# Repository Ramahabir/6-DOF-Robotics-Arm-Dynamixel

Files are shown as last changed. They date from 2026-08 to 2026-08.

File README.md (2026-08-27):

# STM32F411 6-DOF Robot Arm Controller

Firmware for a 6-degree-of-freedom robot arm based on an STM32F411CEU6 (Black Pill). The controller is designed to operate four Dynamixel joints over a half-duplex serial bus and two conventional PWM servos for the end effector.

The project uses STM32Cube HAL with PlatformIO and is uploaded/debugged through ST-Link.

## System overview

- **4 × Dynamixel joints** — controlled through USART2 using Dynamixel Protocol 1.0
- **1 × wrist/gripper rotation servo** — PWM output on PA8
- **1 × gripper servo** — PWM output on PA6
- **USB-to-TTL data logger** — connected through USART1
- **ESP32-C3 Super Mini** — planned wireless interface through USART6
- **74LS241 buffer** — converts the Dynamixel UART connection into a controlled half-duplex bus

## Hardware

- STM32F411CEU6 Black Pill development board
- Dynamixel AX-series actuators (the driver currently targets the AX-12A control table)
- 74LS241 tri-state buffer for the Dynamixel half-duplex bus
- Two PWM-compatible hobby servos
- USB-to-TTL serial adapter
- ST-Link programmer/debugger
- ESP32-C3 Super Mini (planned)
- Suitable external power supplies for the Dynamixel and hobby servos

## Controller PCB

The repository includes the editable KiCad source for the custom controller PCB. The board combines the STM32F411 Black Pill, ESP32-C3 Super Mini, 74LS241 Dynamixel interface, power input, actuator connectors, and development headers on one carrier board.

Open [`pcb/6dof.kicad_pro`](pcb/6dof.kicad_pro) in **KiCad 9.0 or newer** to view or modify the complete project.

### Schematic

<p align="center">
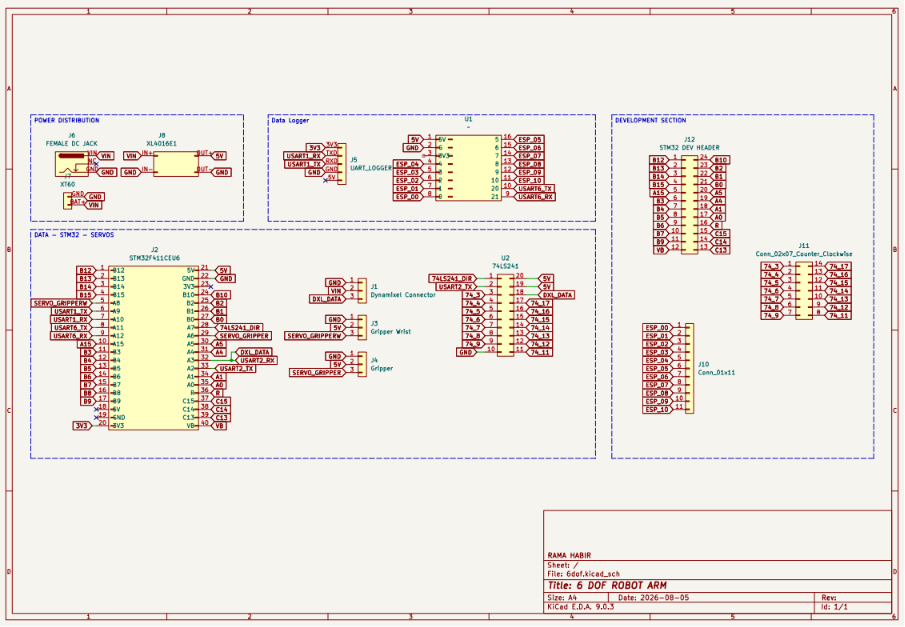
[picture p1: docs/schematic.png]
6-DOF robot arm controller schematic
  
</p>

Editable source: [`pcb/6dof.kicad_sch`](pcb/6dof.kicad_sch)

### PCB layout

<p align="center">
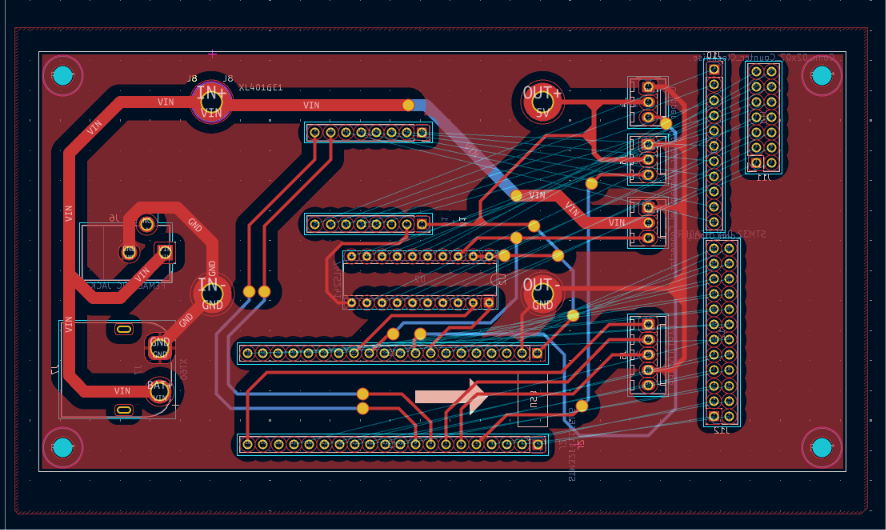
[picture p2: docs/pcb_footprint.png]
6-DOF robot arm controller PCB layout
  
</p>

Editable source: [`pcb/6dof.kicad_pcb`](pcb/6dof.kicad_pcb)

### 3D preview

<p align="center">
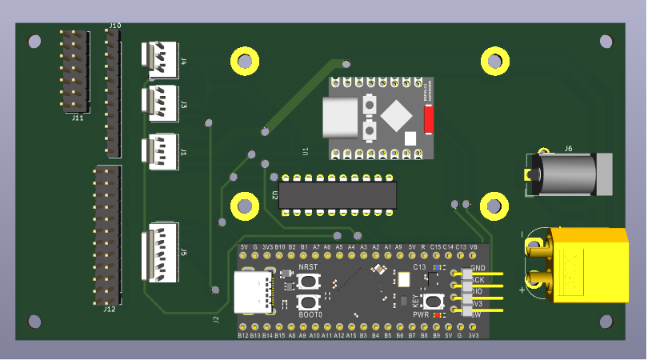
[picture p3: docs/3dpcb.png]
3D preview of the 6-DOF robot arm controller PCB
  
</p>

> The KiCad files are active design sources. Review the schematic, complete the design-rule checks, and verify all footprints and routing before ordering a PCB. Gerber files, drill files, and a bill of materials are not included yet.

## Pin assignment

<p align="center">
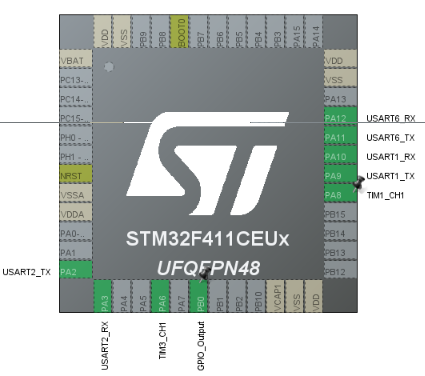
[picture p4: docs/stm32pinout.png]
STM32F411CEU6 robot arm controller pinout
  
</p>

| Function | STM32 peripheral | Pin | Direction | Notes |
|---|---|---:|---|---|
| Dynamixel TX | USART2_TX | PA2 | Output | 1 Mbps, 8-N-1 |
| Dynamixel RX | USART2_RX | PA3 | Input | Receives Dynamixel status packets |
| 74LS241 direction | GPIO | PB0 | Output | High = transmit, low = receive/bus released |
| Data logger TX | USART1_TX | PA9 | Output | Connect to USB-to-TTL RX |
| Data logger RX | USART1_RX | PA10 | Input | Connect to USB-to-TTL TX |
| ESP32-C3 TX | USART6_TX | PA11 | Output | Planned wireless link; connect to ESP32 RX |
| ESP32-C3 RX | USART6_RX | PA12 | Input | Planned wireless link; connect to ESP32 TX |
| Gripper rotation servo | TIM1_CH1 | PA8 | PWM output | Rotates the gripper |
| Gripper servo | TIM3_CH1 | PA6 | PWM output | Opens and closes the gripper |
| Built-in status LED | GPIO | PC13 | Output | Active-low on the Black Pill |

> The USART1 pin assignment above follows the target hardware pinout. The generated firmware currently maps USART1 to PB6/PB7; update the alternate-function configuration to PA9/PA10 before wiring the logger to those target pins.

## Dynamixel bus

Dynamixel Protocol 1.0 uses a single bidirectional data wire. USART2 provides separate TX and RX signals, so the 74LS241 is used to control when the STM32 drives the bus.

```text
STM32 PA2 (USART2_TX) ──> 74LS241 input
STM32 PB0 (DIR)       ──> 74LS241 output-enable/direction control
74LS241 bus output    ──> Dynamixel DATA
STM32 PA3 (USART2_RX) <── Dynamixel DATA / receive path

STM32 GND ─────────────── Dynamixel interface GND
```

The firmware sets PB0 high while transmitting and returns it low before waiting for a servo response. USART2 is configured for **1,000,000 baud, 8 data bits, no parity, and 1 stop bit**.

Do not power the actuators from the STM32 board. Use correctly rated external supplies and connect the grounds of the STM32, servo supplies, Dynamixel bus, USB-to-TTL adapter, and ESP32 interface.

## Joint IDs and calibration

The earlier arm configuration stored in this repository uses the following IDs and zero offsets:

| Joint | Dynamixel ID | Home position | Approx. offset | Positive direction |
|---|---:|---:|---:|---|
| Base | 1 | 493 | 144.57° | Counterclockwise |
| Shoulder | 9 | 308 | 90.32° | Counterclockwise |
| Elbow | 13 | 481 | 141.35° | Counterclockwise |

The current test program in `src/main.c` controls **Dynamixel ID 4**, moving it between raw positions 350 and 650. Confirm every actuator ID and mechanical zero before enabling torque on the assembled arm.

For AX-series position control, raw values `0..1023` represent approximately `0..300°`:

```text
angle = raw_position × 300 / 1023
```

## Firmware status

Currently implemented:

- USART2 Dynamixel Protocol 1.0 communication at 1 Mbps
- Half-duplex direction control through PB0
- Ping, 8/16-bit read and write, torque, LED, goal-position, speed, and present-position commands
- Packet validation for ID, length, checksum, timeout, and servo-reported errors
- TIM1 channel 1 configuration for PA8
- TIM3 channel 1 configuration for PA6
- USART1 configuration at 115200 baud

Still to be integrated into the active application:

- Move the USART1 GPIO mapping from PB6/PB7 to PA9/PA10
- Initialize TIM1 and TIM3 and start both PWM channels
- Add coordinated control for all six axes
- Define the command protocol between the STM32 and ESP32-C3

### LaserPING mapping data logger

When `SERVO_ONLY_TEST` is set to `0` in `src/main.c`, the active control loop
outputs one machine-readable record for every completed LaserPING measurement
on USART1 and USART6 at 115200 baud:

```text
LP,timestamp_ms,q1_raw,q2_raw,q3_raw,q4_raw,distance_mm,status
```

Example:

```text
LP,12540,512,315,487,530,428,0
```

The joint fields are measured Dynamixel present positions, not commanded goal
positions. `status` is a bitmask; zero means the laser result and all four joint
reads are valid. Invalid sensor distances are emitted as zero rather than
repeating a stale measurement.

| Bit | Value | Meaning |
|---:|---:|---|
| 0 | 1 | Laser out of range |
| 1 | 2 | Laser sensor error |
| 2 | 4 | Laser timeout or other invalid laser state |
| 4 | 16 | Base Dynamixel read failed |
| 5 | 32 | Shoulder Dynamixel read failed |
| 6 | 64 | Elbow Dynamixel read failed |
| 7 | 128 | Wrist Dynamixel read failed |

`SERVO_ONLY_TEST` intentionally remains enabled by default because full mode
enables Dynamixel torque and runs the existing startup movement sequence. Verify
joint IDs, limits, clearances, and emergency-stop access before changing it.

In the default servo-only test mode, `main()` initializes GPIO, TIM3, USART1,
and USART6. Full robot mode additionally initializes TIM4 for LaserPING and
USART2 for the Dynamixel bus.

## Building and uploading

### Requirements

- [Visual Studio Code](https://code.visualstudio.com/) with the PlatformIO extension, or PlatformIO Core
- ST-Link programmer connected to SWDIO, SWCLK, GND, and 3.3 V reference

### PlatformIO commands

Build the firmware:

```sh
pio run
```

Upload through ST-Link:

```sh
pio run --target upload
```

Open the serial monitor for logger output once USART1 logging is enabled:

```sh
pio device monitor --baud 115200
```

The PlatformIO environment is `genericSTM32F411CE`, using the STM32Cube framework and ST-Link for upload and debugging.

## Project structure

```text
.
├── include/
│   ├── dynamixel.h       # Dynamixel driver API and control-table addresses
│   ├── gpio.h
│   ├── main.h
│   ├── tim.h
│   └── usart.h
├── docs/
│   ├── 3dpcb.png         # Render of the assembled controller PCB
│   ├── pcb_footprint.png # PCB routing and footprint preview
│   ├── schematic.png     # Controller schematic preview
│   └── stm32pinout.png   # STM32 peripheral pin assignment
├── pcb/
│   ├── 6dof.kicad_pcb    # Editable PCB layout
│   ├── 6dof.kicad_pro    # KiCad project settings
│   └── 6dof.kicad_sch    # Editable schematic
├── src/
│   ├── dynamixel.c       # Protocol 1.0 packet transport and commands
│   ├── gpio.c            # LED and 74LS241 direction GPIO setup
│   ├── main.c            # Active test application
│   ├── tim.c             # PA8 and PA6 PWM timer configuration
│   └── usart.c           # USART1 and USART2 configuration
├── main_lama/            # Earlier application code kept for reference
└── platformio.ini        # PlatformIO target and build configuration
```

## Safety notes

- Test one actuator at a time before operating the complete arm.
- Verify Dynamixel IDs and baud rates before enabling torque.
- Keep the arm clear of people and objects during first motion tests.
- Use a current-limited actuator supply and provide an accessible emergency power cutoff.
- Set conservative position and speed limits in software to prevent mechanical collisions.
- Never connect 5 V logic directly to a non-5-V-tolerant STM32 input; verify the complete 74LS241 interface and supply arrangement before powering it.

## License

This project is open-source software available under the [MIT License](LICENSE).

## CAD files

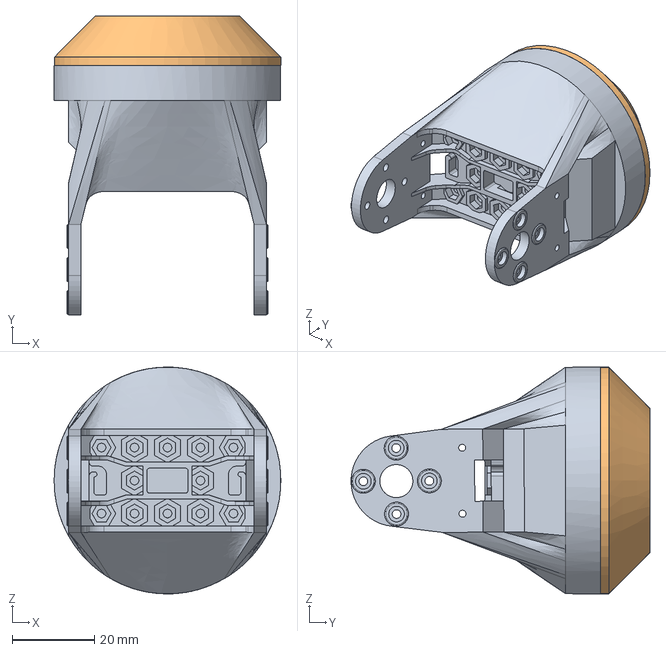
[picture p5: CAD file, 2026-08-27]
cad/Gripper_Laser_Ping.step
55.0 x 72.5 x 55.0 mm

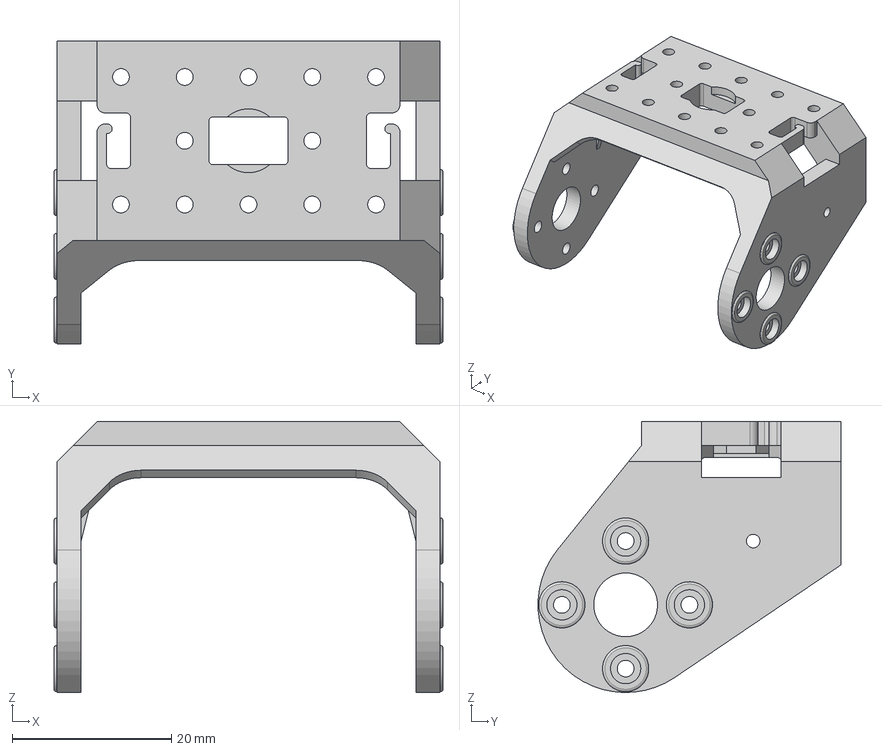
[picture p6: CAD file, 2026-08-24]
cad/base_to_shoulder.step
48.8 x 38.0 x 34.0 mm

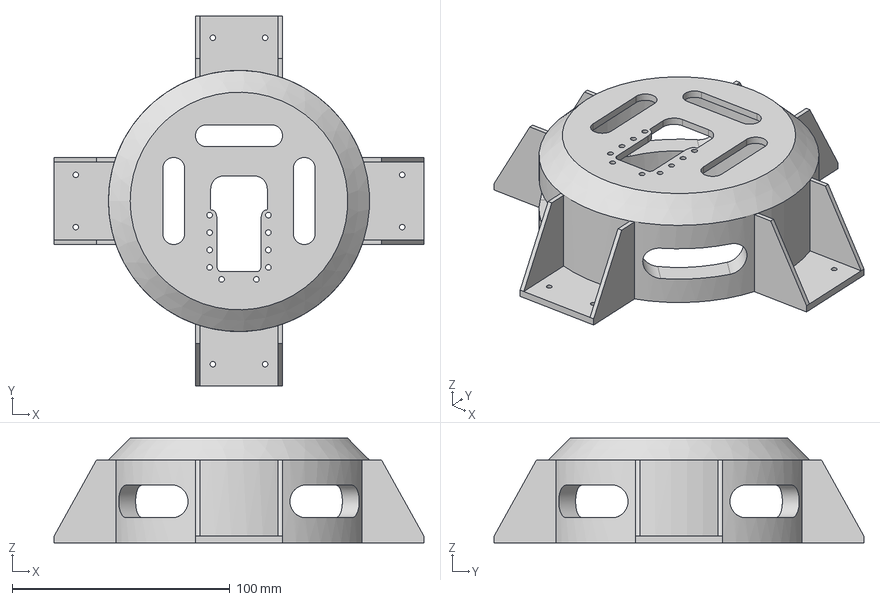
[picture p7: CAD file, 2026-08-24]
cad/enclosure.step
170.0 x 170.0 x 48.2 mm

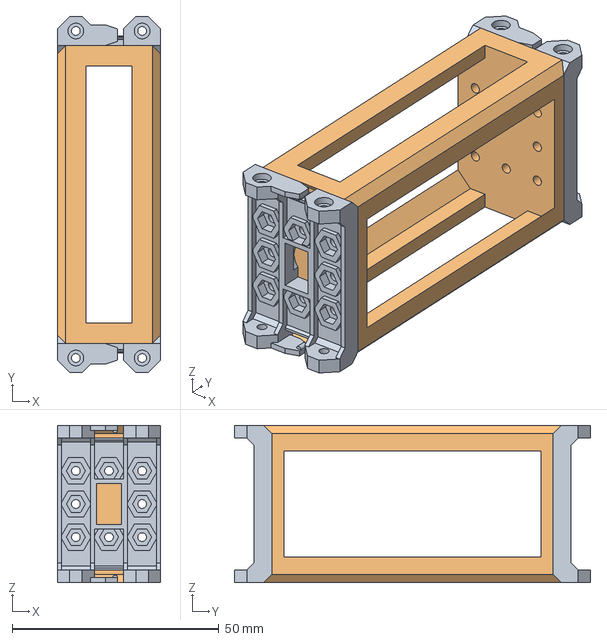
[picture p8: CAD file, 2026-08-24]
cad/elbow.step
25.0 x 86.0 x 38.0 mm
F3
F3_1

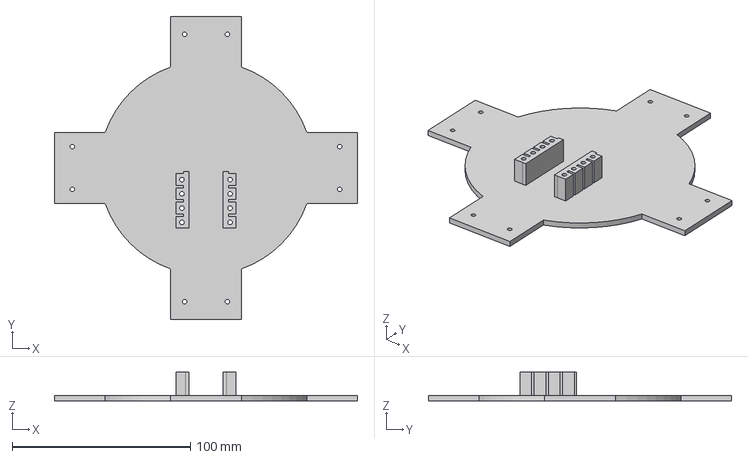
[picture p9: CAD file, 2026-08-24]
cad/enclosure_2.step
170.0 x 170.0 x 16.1 mm

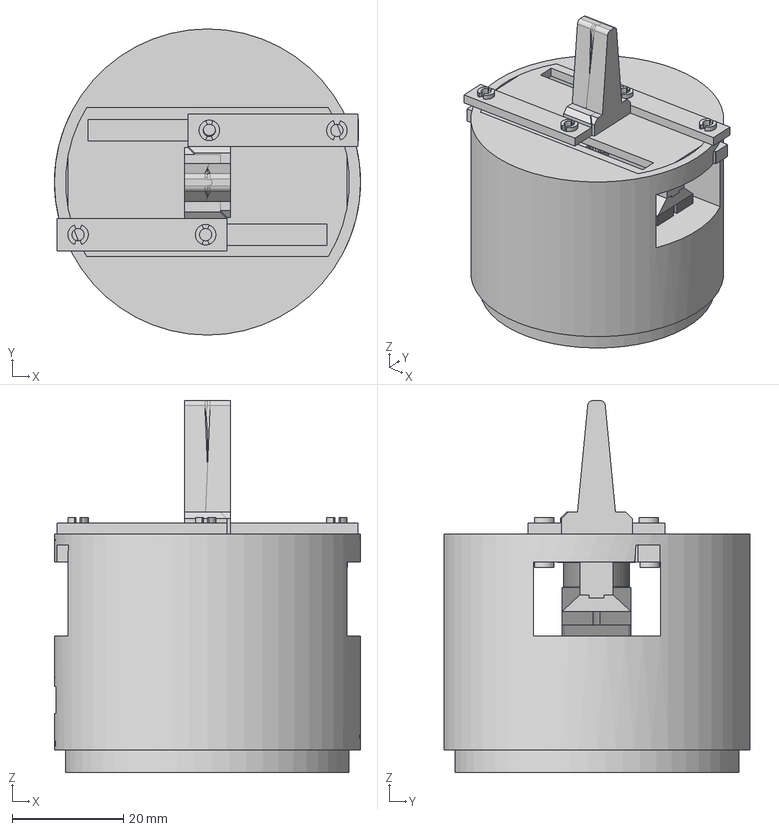
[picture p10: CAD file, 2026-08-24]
cad/gripper.step
55.0 x 55.0 x 66.8 mm
MG90S Servo Motor
Spur Gear 12 teeth
base
rack1
rack1_1
base_jaw
jaw x 2

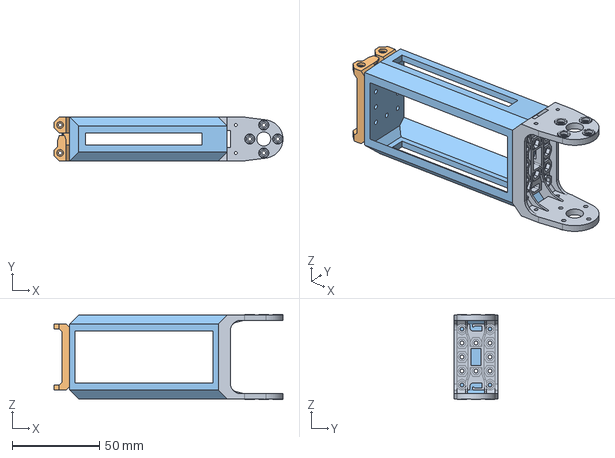
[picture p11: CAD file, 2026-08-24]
cad/shoulder.step
131.0 x 25.0 x 48.8 mm
F2
F3

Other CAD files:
cad/Gripper_Laser_Ping.3mf

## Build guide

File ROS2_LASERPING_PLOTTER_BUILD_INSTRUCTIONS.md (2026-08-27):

# Build Instructions: ROS 2 LaserPING Robot-Arm Plotter Prototype

## Objective

Build a working prototype that reads four Dynamixel joint positions and one LaserPING distance measurement from an STM32 over a serial connection, records the synchronized samples, converts each valid laser measurement into a 3D point using the robot arm kinematics, and displays the accumulated result in RViz 2 as a point cloud.

This is a prototype. Prefer a simple, observable, configurable implementation over premature optimization. Do not invent final mechanical dimensions or calibration values. Put unknown values in configuration files, document them clearly, and provide safe example defaults.

## First action in the target workspace

Before editing anything:

1. Inspect the repository structure, README, build system, existing ROS packages, STM32 firmware, URDF/Xacro files, and any serial or Dynamixel code.
2. Preserve unrelated user changes.
3. Reuse existing drivers, robot descriptions, naming conventions, and package structure where practical.
4. Determine the ROS 2 distribution from the workspace or environment. If it cannot be determined, target ROS 2 Jazzy and clearly document that assumption.
5. Report any pin, joint-ID, timer, UART, link-length, joint-direction, or laser-mount conflicts found in the repository before changing those specific values.

## Prototype architecture

Use this data path:

```text
Dynamixel encoders + LaserPING
              |
              v
           STM32
              |  newline-delimited CSV over USB/UART
              v
     laserping_serial_node
        |              |
        |              +--> sensor_msgs/JointState
        |              +--> sensor_msgs/Range
        |              +--> CSV log file
        v
   robot_state_publisher + URDF/Xacro
              |
              v
       TF base_link -> laser_frame
              |
              v
    laserping_cloud_node
              |
              v
 sensor_msgs/PointCloud2 -> RViz 2
```

The STM32 supplies raw measurements. ROS 2 is responsible for parsing, timestamp conversion, calibration, robot transforms, point generation, recording, and visualization.

## Required logged values

Each measurement record must contain:

```text
timestamp_ms,q1_raw,q2_raw,q3_raw,q4_raw,distance_mm,status
```

Definitions:

- `timestamp_ms`: monotonic STM32 time from boot, preferably captured as close as possible to the measurement set.
- `q1_raw` through `q4_raw`: measured/present Dynamixel positions, not commanded goal positions.
- `distance_mm`: measured LaserPING distance.
- `status`: `0` for a valid synchronized sample; use nonzero values for laser timeout, out-of-range, Dynamixel read failure, or another invalid condition.

Recommended prototype line format:

```text
LP,12540,512,315,487,530,428,0
```

Field order:

```text
LP,timestamp_ms,q1_raw,q2_raw,q3_raw,q4_raw,distance_mm,status
```

Requirements for the serial protocol:

- One complete record per line, terminated with `\n` (accept `\r\n` on the receiver).
- ASCII only for the first prototype.
- Prefix data records with `LP,` so diagnostic text can be ignored safely.
- Do not include units, degree symbols, labels, or spaces in data records.
- Emit at a configurable rate, initially 5-10 Hz.
- A record is valid only when all four present-position reads and the laser measurement succeeded.
- Do not output stale laser distance as a valid new sample.
- Keep human-readable startup messages distinct from `LP,` records.

If firmware changes are in scope in the target repository, implement this output there. If they are not in scope, build the ROS side against a mock serial source and document the exact firmware record that is still required.

## ROS 2 workspace deliverables

Create or extend a ROS 2 package named `laserping_mapper`. Python (`ament_python` and `rclpy`) is acceptable and preferred for fast prototyping unless the target repository already establishes a C++ convention.

Expected files, adapted to the existing workspace layout:

```text
laserping_mapper/
├── package.xml
├── setup.py
├── setup.cfg
├── resource/laserping_mapper
├── laserping_mapper/
│   ├── __init__.py
│   ├── serial_node.py
│   └── cloud_node.py
├── config/
│   ├── mapper.yaml
│   └── joint_calibration.yaml
├── launch/
│   └── mapper.launch.py
├── rviz/
│   └── laserping_mapper.rviz
├── urdf/
│   └── prototype_arm.urdf.xacro
├── test/
│   ├── test_parser.py
│   └── test_geometry.py
└── README.md
```

If a robot-description package already exists, put the URDF/Xacro there instead of duplicating it.

## `laserping_serial_node`

Implement a node that:

1. Opens a configurable serial port with configurable baud rate; default to `115200` baud.
2. Reads newline-delimited records without blocking the ROS executor indefinitely.
3. Ignores diagnostic lines that do not begin with `LP,`.
4. Strictly validates field count, integer conversion, raw-position bounds, distance bounds, and status.
5. Converts raw Dynamixel positions to joint angles in radians using per-joint calibration.
6. Publishes `sensor_msgs/msg/JointState` on `/joint_states`.
7. Publishes `sensor_msgs/msg/Range` on `/laserping/range` for every valid laser sample.
8. Records accepted source samples to a CSV file when logging is enabled.
9. Publishes diagnostics or throttled warnings for malformed records and invalid samples without crashing.
10. Supports a `mock_mode` parameter so the complete ROS pipeline can be demonstrated without hardware.

Use these parameters:

```yaml
serial_port: /dev/ttyUSB0
baud_rate: 115200
serial_timeout_s: 0.05
mock_mode: false
publish_rate_hz: 10.0
base_frame: base_link
laser_frame: laser_frame
range_min_m: 0.02
range_max_m: 3.0
field_of_view_rad: 0.01
log_enabled: true
log_directory: ""
```

An empty `log_directory` should resolve to a documented, user-writable default. Do not write logs inside an installed ROS package.

### Time handling

Use the ROS receipt time for message headers in the first prototype. Also retain `timestamp_ms` in the CSV. Track the STM32 timestamp for dropped/out-of-order records and handle its 32-bit wraparound safely. Do not pretend the STM32 boot clock is Unix or ROS wall time.

### Joint calibration

Do not use an absolute difference from home; doing so destroys the sign of the joint angle. Use:

```text
q_rad = direction * (raw_position - home_raw) * radians_per_tick
```

For an AX-series actuator whose 0-1023 range represents 0-300 degrees:

```text
radians_per_tick = radians(300.0 / 1023.0)
```

Store these values per joint in `joint_calibration.yaml`:

```yaml
joints:
  - name: joint_1
    home_raw: 512
    direction: 1
    min_raw: 0
    max_raw: 1023
  - name: joint_2
    home_raw: 512
    direction: 1
    min_raw: 0
    max_raw: 1023
  - name: joint_3
    home_raw: 512
    direction: 1
    min_raw: 0
    max_raw: 1023
  - name: joint_4
    home_raw: 512
    direction: 1
    min_raw: 0
    max_raw: 1023
ticks_per_range: 1023.0
range_degrees: 300.0
```

Treat all example home positions and directions as placeholders until verified on the physical arm.

## Robot description and transforms

Create or reuse a URDF/Xacro model containing:

- `base_link`
- Four revolute joints with names matching `/joint_states`
- Corresponding arm links
- A fixed transform from the final arm link to `laser_frame`

The fixed laser transform must include both translation and rotation. Its positive X axis should represent the emitted laser ray unless the existing robot convention specifies another axis. Document the chosen ray axis.

Put link lengths, joint axes, joint origins, joint limits, and the laser mounting transform in Xacro properties or YAML-accessible configuration. Clearly label unmeasured geometry as placeholder values.

Launch `robot_state_publisher` with the resulting `robot_description`. Do not manually reimplement the complete forward-kinematics chain in the cloud node if TF already supplies `base_link -> laser_frame`.

## `laserping_cloud_node`

Implement a node that converts each valid range observation into a point in `base_link`.

If the laser ray is the positive X axis of `laser_frame`, the local hit is:

```text
p_laser = [distance_m, 0, 0]
```

Transform that point into `base_link` using TF at the measurement header timestamp:

```text
p_base = T_base_laser * p_laser
```

This is equivalent to:

```text
hit_position = laser_origin + distance * laser_direction
```

Important: laser origin `(x, y, z)` plus distance alone is insufficient. The orientation/direction from TF is required.

Node behavior:

- Subscribe to `/laserping/range`.
- Look up `base_link -> laser_frame` from `tf2_ros` using the range message timestamp.
- Reject samples cleanly when TF is unavailable or distance is invalid.
- Append accepted hits to an in-memory point collection.
- Publish the accumulated points as `sensor_msgs/msg/PointCloud2` on `/laserping/points`.
- Use `base_link` as the point-cloud frame.
- Make maximum retained points configurable, for example `max_points: 20000`, dropping the oldest points when full.
- Provide a reset mechanism, preferably a `std_srvs/srv/Empty` service at `/laserping/clear_map`.
- Optionally publish the newest hit separately on `/laserping/latest_point`.
- Do not use LaserScan unless the motion pattern actually guarantees an ordered planar angular scan.

For this prototype, XYZ-only `float32` PointCloud2 fields are sufficient.

## Data logging

The CSV log should contain both raw measurements and useful ROS-side results:

```text
ros_time_ns,stm32_timestamp_ms,q1_raw,q2_raw,q3_raw,q4_raw,q1_rad,q2_rad,q3_rad,q4_rad,distance_mm,status,hit_x_m,hit_y_m,hit_z_m
```

If a transform is temporarily unavailable, preserve the valid raw sample and leave hit coordinates empty, or place it in a separate raw CSV. Document the chosen behavior.

Flush periodically and close the file cleanly. Include a timestamp in each log filename so previous sessions are not overwritten.

## Launch and RViz

Provide one launch command that starts:

- `laserping_serial_node`
- `robot_state_publisher`
- `laserping_cloud_node`
- RViz 2 optionally through a launch argument

Example expected command:

```bash
ros2 launch laserping_mapper mapper.launch.py \
  serial_port:=/dev/ttyUSB0 \
  mock_mode:=false \
  use_rviz:=true
```

The RViz configuration should include:

- Fixed Frame: `base_link`
- RobotModel
- TF
- PointCloud2 display for `/laserping/points`
- Range display for `/laserping/range`, if supported and useful

## Mock mode

Mock mode is required so the software can be tested before connecting the arm. It should generate a slow, safe synthetic four-joint motion and plausible range measurements. It must use the same parser/publication path as real input wherever practical.

Provide at least one deterministic mock sequence that generates a visibly recognizable arc, plane, or box-like surface in RViz. Mark mock records clearly in logs or diagnostics.

## Dependencies

Declare all used dependencies correctly in `package.xml` and packaging metadata. Likely dependencies include:

- `rclpy`
- `sensor_msgs`
- `geometry_msgs`
- `std_srvs`
- `tf2_ros`
- `tf2_geometry_msgs`
- `robot_state_publisher`
- `xacro`
- Python `pyserial`

Use repository/environment conventions for dependency management. Document any required `rosdep` and serial-port permission commands; do not silently modify system groups or permissions.

## Tests

At minimum, add automated tests for:

1. Parsing a valid `LP,` line.
2. Rejecting wrong prefixes, field counts, non-integer fields, invalid status, out-of-bounds encoder values, and invalid distances.
3. Signed encoder-to-radian calibration on both sides of the home position.
4. Laser hit geometry for identity transform.
5. Laser hit geometry for a known translation and rotation.
6. Maximum point-buffer behavior.
7. STM32 timestamp wraparound/out-of-order handling if that logic is separated enough to test.

Run the appropriate checks, such as:

```bash
colcon build --symlink-install
source install/setup.bash
colcon test
colcon test-result --verbose
```

Adapt shell syntax for the actual operating system and ROS environment.

## Prototype acceptance criteria

The prototype is complete when:

1. The ROS workspace builds cleanly.
2. Parser and geometry tests pass.
3. Mock mode launches without hardware and publishes all expected topics.
4. `/joint_states` contains four correctly named joints in radians.
5. TF provides a connected chain from `base_link` to `laser_frame`.
6. `/laserping/range` publishes valid range messages in metres.
7. `/laserping/points` accumulates visible XYZ hits in RViz 2.
8. `/laserping/clear_map` clears the accumulated points.
9. A timestamped CSV log is created without overwriting earlier runs.
10. Malformed serial input produces a throttled warning rather than terminating a node.
11. The README explains setup, configuration, launch, calibration, logging, and known prototype limitations.

## Safety and limitations

- Begin with torque disabled or the arm physically supported while verifying encoder signs and zero positions.
- Verify joint IDs and mechanical limits before commanding motion.
- Use low speed and conservative motion limits for initial scans.
- Keep an accessible actuator power cutoff.
- Reject distances outside the configured valid sensor range.
- A moving base requires an additional localization transform; this prototype maps only relative to a stationary `base_link`.
- Accuracy depends on link dimensions, joint zero calibration, backlash, arm flex, laser mounting alignment, sensor noise, and timestamp skew.
- Four joints can position and orient the laser only within the arm's actual kinematic constraints; this is not equivalent to a general-purpose 6-DOF scanner.
- Do not claim metric map accuracy until geometry and laser extrinsics have been physically calibrated.

## Implementation handoff

When finished, provide:

1. A concise summary of created and modified files.
2. Exact build, test, and launch commands.
3. Test results.
4. Assumed ROS 2 distribution and operating system.
5. A table of every placeholder requiring physical measurement or verification, especially:
   - serial device name;
   - Dynamixel IDs;
   - home encoder values;
   - joint directions;
   - joint axes and limits;
   - link lengths and joint origins;
   - laser mounting translation and rotation;
   - laser valid range;
   - scan motion or sampling rate.
6. Any remaining firmware work needed to emit the specified `LP,` serial records.

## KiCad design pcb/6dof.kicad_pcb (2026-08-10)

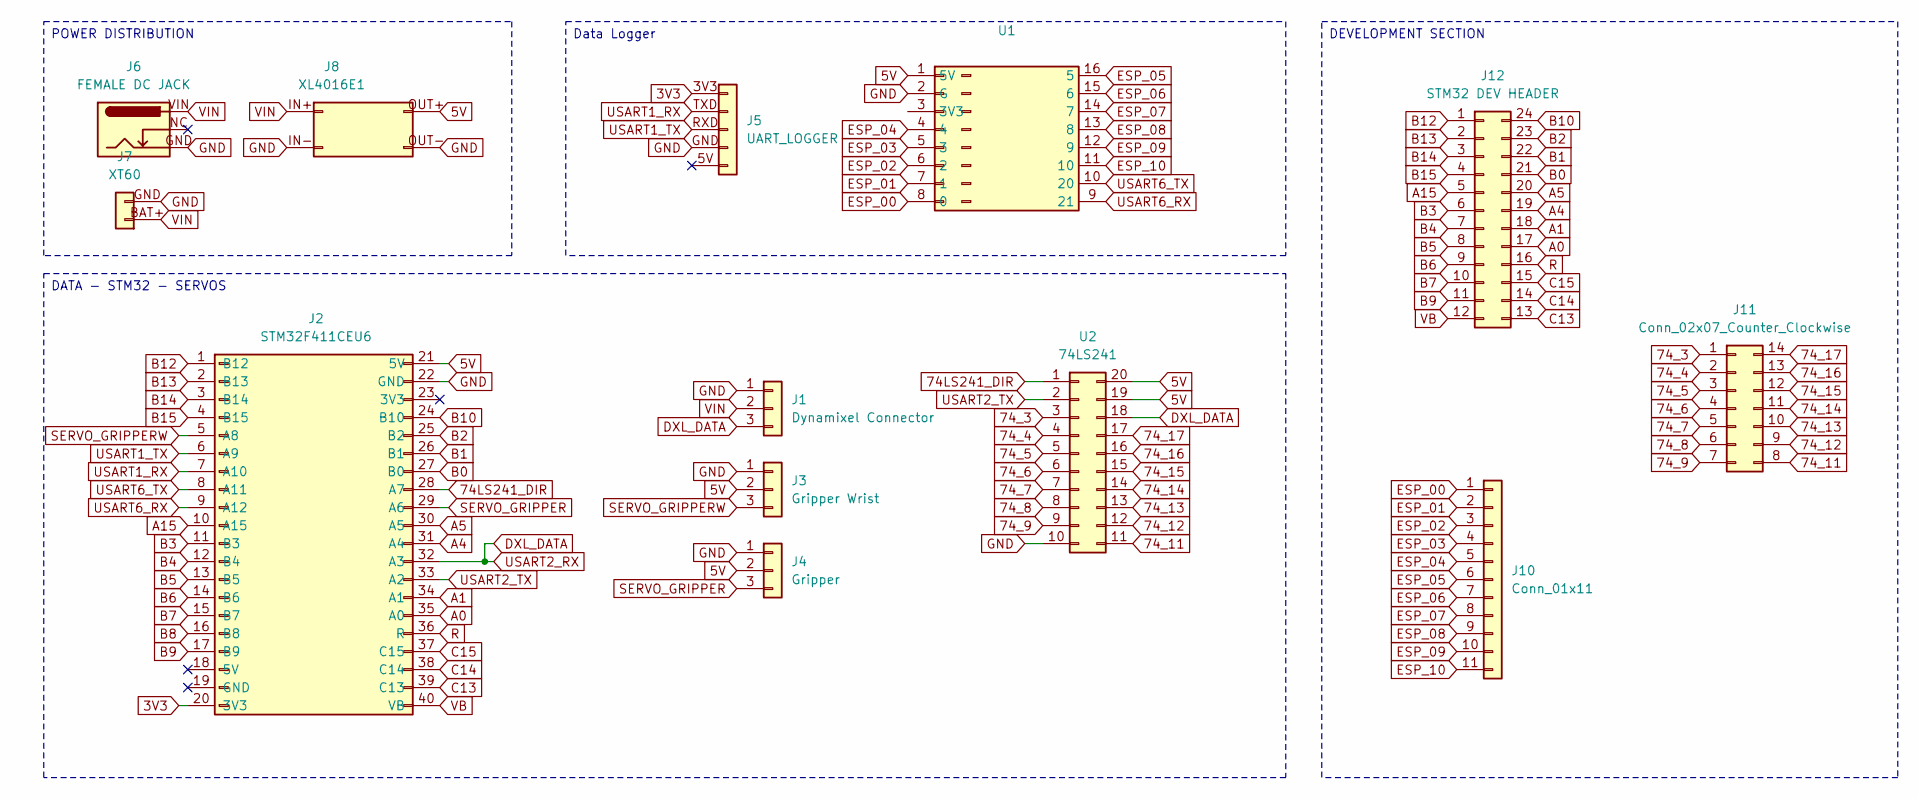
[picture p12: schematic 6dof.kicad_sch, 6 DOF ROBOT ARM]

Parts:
J1: Dynamixel Connector; Molex_KK-254_AE-6410-03A_1x03_P2.54mm_Vertical
J2: STM32F411CEU6
J3: Gripper Wrist; Molex_KK-254_AE-6410-03A_1x03_P2.54mm_Vertical
J4: Gripper; Molex_KK-254_AE-6410-03A_1x03_P2.54mm_Vertical
J5: UART_LOGGER; Molex_KK-254_AE-6410-05A_1x05_P2.54mm_Vertical
J6: FEMALE DC JACK; BarrelJack_CUI_PJ-102AH_Horizontal
J7: XT60; AMASS_XT60PW-M_1x02_P7.20mm_Horizontal
J8: XL4016E1
J10: Conn_01x11; PinHeader_1x11_P2.54mm_Vertical
J11: Conn_02x07_Counter_Clockwise; PinHeader_2x07_P2.54mm_Vertical
J12: STM32 DEV HEADER; PinHeader_2x12_P2.54mm_Vertical
U1: ESP32 C3 SUPERMINI
U2: 74LS241; DIP-20_W7.62mm

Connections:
3V3: J2.20 (3V3), J5.3V3
5V: J2.21 (5V), J3.2, J4.2, J8.OUT+ (Pin_4), U1.1 (5V), U2.19, U2.20
74LS241_DIR: J2.28 (A7), U2.1
74_3: J11.1, U2.3
74_4: J11.2, U2.4
74_5: J11.3, U2.5
74_6: J11.4, U2.6
74_7: J11.5, U2.7
74_8: J11.6, U2.8
74_9: J11.7, U2.9
74_11: J11.8, U2.11
74_12: J11.9, U2.12
74_13: J11.10, U2.13
74_14: J11.11, U2.14
74_15: J11.12, U2.15
74_16: J11.13, U2.16
74_17: J11.14, U2.17
A0: J2.35 (A0), J12.17
A1: J2.34 (A1), J12.18
A4: J2.31 (A4), J12.19
A5: J2.30 (A5), J12.20
A15: J2.10 (A15), J12.5
B0: J2.27 (B0), J12.21
B1: J2.26 (B1), J12.22
B2: J2.25 (B2), J12.23
B3: J2.11 (B3), J12.6
B4: J2.12 (B4), J12.7
B5: J2.13 (B5), J12.8
B6: J2.14 (B6), J12.9
B7: J2.15 (B7), J12.10
B8: J2.16 (B8)
B9: J2.17 (B9), J12.11
B10: J2.24 (B10), J12.24
B12: J2.1 (B12), J12.1
B13: J2.2 (B13), J12.2
B14: J2.3 (B14), J12.3
B15: J2.4 (B15), J12.4
C13: J2.39 (C13), J12.13
C14: J2.38 (C14), J12.14
C15: J2.37 (C15), J12.15
DXL_DATA: J1.3, J2.32 (A3), U2.18
ESP_00: J10.1, U1.8 (0)
ESP_01: J10.2, U1.7 (1)
ESP_02: J10.3, U1.6 (2)
ESP_03: J10.4, U1.5 (3)
ESP_04: J10.5, U1.4
ESP_05: J10.6, U1.16 (5)
ESP_06: J10.7, U1.15 (6)
ESP_07: J10.8, U1.14 (7)
ESP_08: J10.9, U1.13 (8)
ESP_09: J10.10, U1.12 (9)
ESP_10: J10.11, U1.11 (10)
GND: J1.1, J2.22 (GND), J3.1, J4.1, J5.GND, J6.GND, J7.GND (Pin_2), J8.IN- (Pin_2), J8.OUT- (Pin_3), U1.2 (G), U2.10
R: J2.36 (R), J12.16
SERVO_GRIPPER: J2.29 (A6), J4.3
SERVO_GRIPPERW: J2.5 (A8), J3.3
USART1_RX: J2.7 (A10), J5.TXD
USART1_TX: J2.6 (A9), J5.RXD
USART2_TX: J2.33 (A2), U2.2
USART6_RX: J2.9 (A12), U1.9 (21)
USART6_TX: J2.8 (A11), U1.10 (20)
VB: J2.40 (VB), J12.12
VIN: J1.2, J6.VIN, J7.BAT+ (Pin_1), J8.IN+ (Pin_1)

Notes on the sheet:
DATA - STM32 - SERVOS
DEVELOPMENT SECTION
Data Logger
POWER DISTRIBUTION

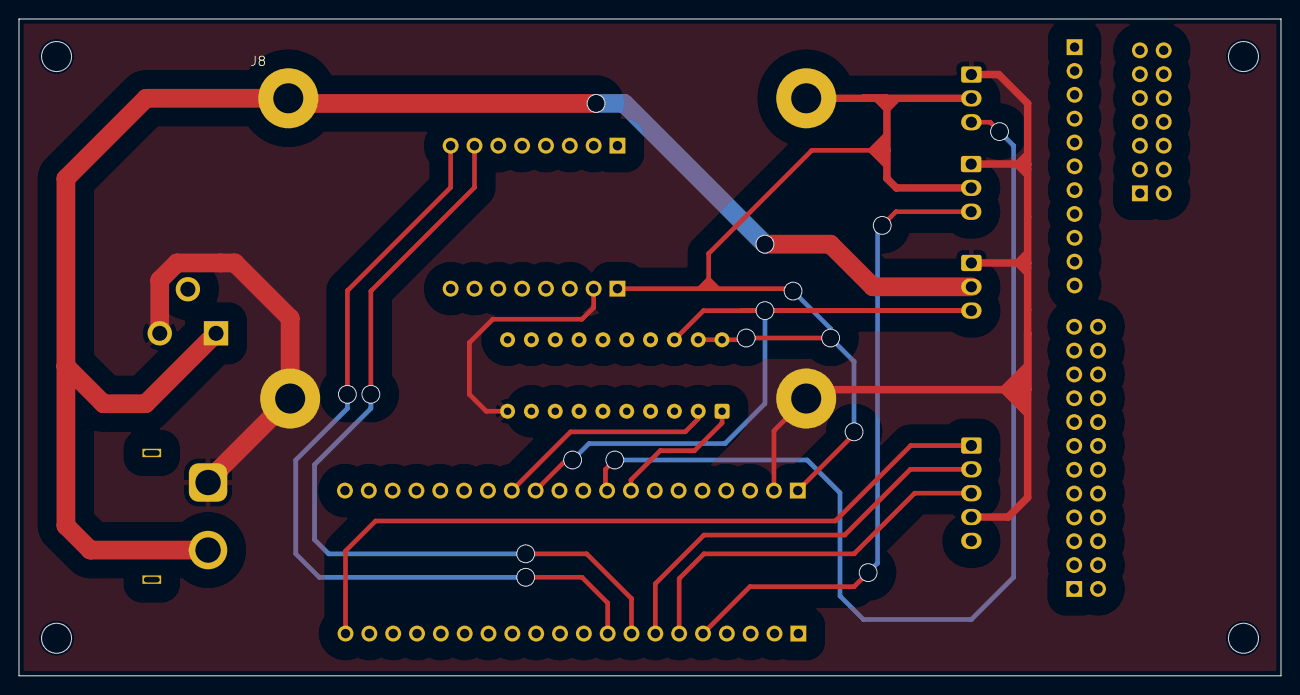
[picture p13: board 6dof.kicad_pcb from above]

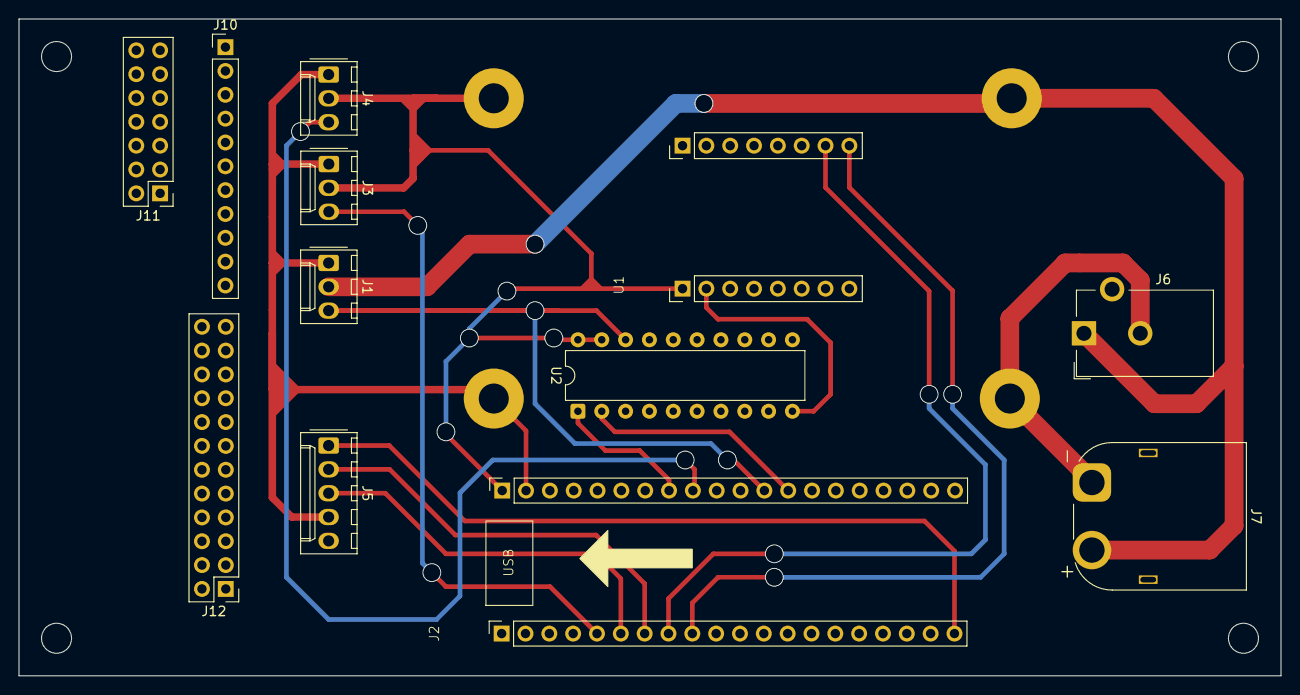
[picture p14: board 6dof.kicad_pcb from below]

Board: 2 copper layers, 134.5 x 70.0 mm, 13 parts (12 on the bottom side), 62 nets.

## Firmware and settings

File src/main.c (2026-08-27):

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
/* Includes ------------------------------------------------------------------*/
#include "main.h"
#include "usart.h"
#include "gpio.h"
#include "tim.h"
#include "dynamixel.h"
#include "laserping.h"
#include <stdio.h>
#include <string.h>

/* USER CODE BEGIN PD */

/* Set to 0 to restore the complete robot-arm application. */
#define SERVO_ONLY_TEST 0

/* USER CODE END PD */


/* USER CODE BEGIN PV */
#if !SERVO_ONLY_TEST
static DXL_HandleTypeDef hdxl;

#define BASE_ID       1U
#define SHOULDER_ID   9U
#define ELBOW_ID     13U
#define WRIST_ID       3U

#define TARGET_BASE_POS    512U
#define TARGET_SHOULDER_POS 315U
#define TARGET_ELBOW_POS   512U
#define TARGET_WRIST_POS   512U
#define POSITION_TOLERANCE  5U

/* Home position offsets - these will be displayed as 0 degrees */
#define HOME_BASE_POS       512U
#define HOME_SHOULDER_POS   315U
#define HOME_ELBOW_POS      512U
#define HOME_WRIST_POS      512U

/*
 * Machine-readable logger status bitmask. A value of zero means that the
 * LaserPING result and all four present-position reads are valid.
 */
#define LOGGER_STATUS_LASER_OUT_OF_RANGE  (1U << 0)
#define LOGGER_STATUS_LASER_SENSOR_ERROR  (1U << 1)
#define LOGGER_STATUS_LASER_TIMEOUT       (1U << 2)
#define LOGGER_STATUS_BASE_ERROR          (1U << 4)
#define LOGGER_STATUS_SHOULDER_ERROR      (1U << 5)
#define LOGGER_STATUS_ELBOW_ERROR         (1U << 6)
#define LOGGER_STATUS_WRIST_ERROR         (1U << 7)

#define ANIMATION_POSE_TIMEOUT_MS  5000U
#define ANIMATION_STABLE_READS      3U
#define ANIMATION_POSE_HOLD_MS   2000U

typedef struct
{
  uint16_t base;
  uint16_t shoulder;
  uint16_t elbow;
  uint16_t wrist;
  uint16_t speed;
  uint16_t pause_ms;
} RobotPose;

/*
 * Dramatic "sentinel wake-up" sequence. The wide scan takes about two
 * seconds, depending on servo load and supply voltage. The final pose is home.
 */
static const RobotPose startup_animation[] =
{
  {512U, 315U, 512U, 512U, 50U, ANIMATION_POSE_HOLD_MS}, /* home */
  {392U, 315U, 512U, 512U, 50U, ANIMATION_POSE_HOLD_MS}, /* scan left */
  {632U, 315U, 512U, 512U, 50U, ANIMATION_POSE_HOLD_MS}, /* scan right */
  {512U, 315U, 512U, 512U, 50U, ANIMATION_POSE_HOLD_MS}, /* center */
  {512U, 365U, 457U, 402U, 30U, ANIMATION_POSE_HOLD_MS}, /* bow */
  {512U, 365U, 457U, 622U, 55U, ANIMATION_POSE_HOLD_MS}, /* wrist flick */
  {512U, 365U, 457U, 512U, 55U, ANIMATION_POSE_HOLD_MS}, /* wrist center */
  {512U, 315U, 512U, 512U, 25U, ANIMATION_POSE_HOLD_MS}  /* home */
};
#endif /* !SERVO_ONLY_TEST */
/* USER CODE END PV */

void SystemClock_Config(void);
/* USER CODE BEGIN PFP */
#if !SERVO_ONLY_TEST
static bool Robot_MoveToPose(const RobotPose *pose, uint32_t timeout_ms);
static bool Robot_PlayStartupAnimation(void);
#endif
/* USER CODE END PFP */

/* USER CODE BEGIN 0 */
#if !SERVO_ONLY_TEST
static uint16_t PositionDifference(uint16_t actual, uint16_t target)
{
  return (actual > target) ? (actual - target) : (target - actual);
}

static bool Robot_MoveToPose(const RobotPose *pose, uint32_t timeout_ms)
{
  uint16_t base;
  uint16_t shoulder;
  uint16_t elbow;
  uint16_t wrist;
  uint32_t start_ms;
  uint8_t stable_reads = 0U;

  if (pose == NULL)
  {
    return false;
  }

  if ((DXL_SetMovingSpeed(&hdxl, BASE_ID, pose->speed) != DXL_OK) ||
      (DXL_SetMovingSpeed(&hdxl, SHOULDER_ID, pose->speed) != DXL_OK) ||
      (DXL_SetMovingSpeed(&hdxl, ELBOW_ID, pose->speed) != DXL_OK) ||
      (DXL_SetMovingSpeed(&hdxl, WRIST_ID, pose->speed) != DXL_OK))
  {
    return false;
  }

  if ((DXL_SetGoalPosition(&hdxl, BASE_ID, pose->base) != DXL_OK) ||
      (DXL_SetGoalPosition(&hdxl, SHOULDER_ID, pose->shoulder) != DXL_OK) ||
      (DXL_SetGoalPosition(&hdxl, ELBOW_ID, pose->elbow) != DXL_OK) ||
      (DXL_SetGoalPosition(&hdxl, WRIST_ID, pose->wrist) != DXL_OK))
  {
    return false;
  }

  start_ms = HAL_GetTick();
  while ((HAL_GetTick() - start_ms) < timeout_ms)
  {
    bool at_target =
        (DXL_GetPresentPosition(&hdxl, BASE_ID, &base) == DXL_OK) &&
        (DXL_GetPresentPosition(&hdxl, SHOULDER_ID, &shoulder) == DXL_OK) &&
        (DXL_GetPresentPosition(&hdxl, ELBOW_ID, &elbow) == DXL_OK) &&
        (DXL_GetPresentPosition(&hdxl, WRIST_ID, &wrist) == DXL_OK) &&
        (PositionDifference(base, pose->base) <= POSITION_TOLERANCE) &&
        (PositionDifference(shoulder, pose->shoulder) <= POSITION_TOLERANCE) &&
        (PositionDifference(elbow, pose->elbow) <= POSITION_TOLERANCE) &&
        (PositionDifference(wrist, pose->wrist) <= POSITION_TOLERANCE);

    if (at_target)
    {
      stable_reads++;
      if (stable_reads >= ANIMATION_STABLE_READS)
      {
        HAL_Delay(pose->pause_ms);
        return true;
      }
    }
    else
    {
      stable_reads = 0U;
    }

    HAL_Delay(40U);
  }

  return false;
}

static bool Robot_PlayStartupAnimation(void)
{
  size_t pose_index;
  const size_t pose_count =
      sizeof(startup_animation) / sizeof(startup_animation[0]);

  for (pose_index = 0U; pose_index < pose_count; pose_index++)
  {
    if (!Robot_MoveToPose(&startup_animation[pose_index],
                          ANIMATION_POSE_TIMEOUT_MS))
    {
      return false;
    }
  }

  return true;
}
#endif /* !SERVO_ONLY_TEST */
/* USER CODE END 0 */

/**
  * @brief  The application entry point.
  * @retval int
  */
int main(void)
{

  /* MCU Configuration--------------------------------------------------------*/

  /* Reset of all peripherals, Initializes the Flash interface and the Systick. */
  HAL_Init();

  /* Configure the system clock */
  SystemClock_Config();

  /* Initialize all configured peripherals */
  MX_GPIO_Init();
  MX_TIM3_Init();
  MX_USART1_UART_Init();
  MX_USART6_UART_Init();
#if !SERVO_ONLY_TEST
  MX_TIM4_Init();
  LaserPING_Init(&htim4);
#endif

#if SERVO_ONLY_TEST
  /*
   * Breadboard test mode: MG90S only, with no LaserPING, Dynamixel
   * initialization, or robot movement. USART1 uses PB6/PB7 in this codebase.
  */
  char buffer[128];
  int length;
  uint16_t servo_pulse_us = 1000U;
  int16_t servo_step_us = 10;
  uint32_t last_servo_move_ms;

  /* Start near 0 degrees on PA6/TIM3_CH1. */
  __HAL_TIM_SET_COMPARE(&htim3, TIM_CHANNEL_1, servo_pulse_us);
  if (HAL_TIM_PWM_Start(&htim3, TIM_CHANNEL_1) != HAL_OK)
  {
    Error_Handler();
  }
  last_servo_move_ms = HAL_GetTick();

  HAL_Delay(100U);
  length = snprintf(buffer, sizeof(buffer),
                    "MG90S sweeping 0-180-0 degrees on PA6\r\n");
  if (length > 0)
  {
    (void)HAL_UART_Transmit(&huart1, (uint8_t *)buffer,
                            (uint16_t)length, HAL_MAX_DELAY);
    (void)HAL_UART_Transmit(&huart6, (uint8_t *)buffer,
                            (uint16_t)length, HAL_MAX_DELAY);
  }

  while (1)
  {
    uint32_t now = HAL_GetTick();

    /* Smoothly sweep approximately 0 -> 180 -> 0 degrees. */
    if ((now - last_servo_move_ms) >= 20U)
    {
      int32_t next_pulse_us = (int32_t)servo_pulse_us + servo_step_us;
      const char *endpoint = NULL;

      if (next_pulse_us >= 2000)
      {
        next_pulse_us = 2000;
        servo_step_us = -10;
        endpoint = "180 degrees";
      }
      else if (next_pulse_us <= 1000)
      {
        next_pulse_us = 1000;
        servo_step_us = 10;
        endpoint = "0 degrees";
      }

      servo_pulse_us = (uint16_t)next_pulse_us;
      __HAL_TIM_SET_COMPARE(&htim3, TIM_CHANNEL_1, servo_pulse_us);
      last_servo_move_ms = now;

      if (endpoint != NULL)
      {
        length = snprintf(buffer, sizeof(buffer), "MG90S: %s (%u us)\r\n",
                          endpoint, (unsigned int)servo_pulse_us);
        if (length > 0)
        {
          (void)HAL_UART_Transmit(&huart1, (uint8_t *)buffer,
                                  (uint16_t)length, HAL_MAX_DELAY);
          (void)HAL_UART_Transmit(&huart6, (uint8_t *)buffer,
                                  (uint16_t)length, HAL_MAX_DELAY);
        }
      }
    }

    HAL_Delay(1U);
  }
#else
  MX_USART2_UART_Init();

  /*
   * UART2: PA2=TX, PA3=RX, 1 Mbps, Dynamixel Protocol 1.0.
   * PB0 controls the external half-duplex buffer: high=TX, low=RX.
   */
  DXL_Init(&hdxl, &huart2, GPIOB, GPIO_PIN_0);
  HAL_Delay(500U);

  /* ========== STARTUP INITIALIZATION SEQUENCE ========== */
  uint16_t base_position, shoulder_position, elbow_position, wrist_position;
  uint16_t attempts = 0;
  const uint16_t MAX_ATTEMPTS = 500;  /* ~50 seconds at 100ms polling */
  char buffer[128];
  int length;
  bool init_success = false;

  /* Enable torque on all servos */
  DXL_SetTorque(&hdxl, BASE_ID, true);
  DXL_SetTorque(&hdxl, SHOULDER_ID, true);
  DXL_SetTorque(&hdxl, ELBOW_ID, true);
  DXL_SetTorque(&hdxl, WRIST_ID, true);
  HAL_Delay(100U);

  /* Set moderate movement speed for all servos */
  DXL_SetMovingSpeed(&hdxl, BASE_ID, 256);
  DXL_SetMovingSpeed(&hdxl, SHOULDER_ID, 256);
  DXL_SetMovingSpeed(&hdxl, ELBOW_ID, 256);
  DXL_SetMovingSpeed(&hdxl, WRIST_ID, 256);
  HAL_Delay(100U);

  /* Set initial goal positions */
  DXL_SetGoalPosition(&hdxl, BASE_ID, TARGET_BASE_POS);
  DXL_SetGoalPosition(&hdxl, SHOULDER_ID, TARGET_SHOULDER_POS);
  DXL_SetGoalPosition(&hdxl, ELBOW_ID, TARGET_ELBOW_POS);
  DXL_SetGoalPosition(&hdxl, WRIST_ID, TARGET_WRIST_POS);
  HAL_Delay(500U);

  /* Print startup message */
  length = snprintf(buffer, sizeof(buffer),
                    "Robot startup: Moving to initial position...\r\n");
  if (length > 0) {
    HAL_UART_Transmit(&huart1, (uint8_t *)buffer, (uint16_t)length, HAL_MAX_DELAY);
    HAL_UART_Transmit(&huart6, (uint8_t *)buffer, (uint16_t)length, HAL_MAX_DELAY);
  }

  /* Wait for all servos to reach target positions */
  while (attempts < MAX_ATTEMPTS && !init_success) {
    DXL_Result base_result = DXL_GetPresentPosition(&hdxl, BASE_ID, &base_position);
    DXL_Result shoulder_result = DXL_GetPresentPosition(&hdxl, SHOULDER_ID, &shoulder_position);
    DXL_Result elbow_result = DXL_GetPresentPosition(&hdxl, ELBOW_ID, &elbow_position);
    DXL_Result wrist_result = DXL_GetPresentPosition(&hdxl, WRIST_ID, &wrist_position);

    /* Check if all positions are within tolerance */
    if ((base_result == DXL_OK) && (shoulder_result == DXL_OK) &&
        (elbow_result == DXL_OK) && (wrist_result == DXL_OK)) {
      
      int base_diff = (base_position > TARGET_BASE_POS) ? 
                      (base_position - TARGET_BASE_POS) : 
                      (TARGET_BASE_POS - base_position);
      int shoulder_diff = (shoulder_position > TARGET_SHOULDER_POS) ? 
                          (shoulder_position - TARGET_SHOULDER_POS) : 
                          (TARGET_SHOULDER_POS - shoulder_position);
      int elbow_diff = (elbow_position > TARGET_ELBOW_POS) ? 
                       (elbow_position - TARGET_ELBOW_POS) : 
                       (TARGET_ELBOW_POS - elbow_position);
      int wrist_diff = (wrist_position > TARGET_WRIST_POS) ? 
                       (wrist_position - TARGET_WRIST_POS) : 
                       (TARGET_WRIST_POS - wrist_position);

      if ((base_diff <= POSITION_TOLERANCE) &&
          (shoulder_diff <= POSITION_TOLERANCE) &&
          (elbow_diff <= POSITION_TOLERANCE) &&
          (wrist_diff <= POSITION_TOLERANCE)) {
        init_success = true;
        break;
      }
    }

    attempts++;
    HAL_Delay(100U);
  }

  /* Print initialization result */
  if (init_success) {
    /* Apply home offset so home position displays as 0 degrees */
    float base_deg = DXL_PositionToAngle(base_position > HOME_BASE_POS ? 
                                         base_position - HOME_BASE_POS : 
                                         HOME_BASE_POS - base_position);
    float shoulder_deg = DXL_PositionToAngle(shoulder_position > HOME_SHOULDER_POS ? 
                                             shoulder_position - HOME_SHOULDER_POS : 
                                             HOME_SHOULDER_POS - shoulder_position);
    float elbow_deg = DXL_PositionToAngle(elbow_position > HOME_ELBOW_POS ? 
                                          elbow_position - HOME_ELBOW_POS : 
                                          HOME_ELBOW_POS - elbow_position);
    float wrist_deg = DXL_PositionToAngle(wrist_position > HOME_WRIST_POS ? 
                                          wrist_position - HOME_WRIST_POS : 
                                          HOME_WRIST_POS - wrist_position);
    length = snprintf(buffer, sizeof(buffer),
                      "[SUCCESS] Robot at initial position: B:%.2f° S:%.2f° E:%.2f° W:%.2f°\r\n",
                      base_deg, shoulder_deg, elbow_deg, wrist_deg);
    HAL_GPIO_WritePin(LED_BUILTIN_GPIO_Port, LED_BUILTIN_Pin, GPIO_PIN_RESET);
  } else {
    length = snprintf(buffer, sizeof(buffer),
                      "[FAILED] Timeout reaching initial position (attempts: %u)\r\n",
                      attempts);
    HAL_GPIO_WritePin(LED_BUILTIN_GPIO_Port, LED_BUILTIN_Pin, GPIO_PIN_SET);
  }

  if (length > 0) {
    HAL_UART_Transmit(&huart1, (uint8_t *)buffer, (uint16_t)length, HAL_MAX_DELAY);
    HAL_UART_Transmit(&huart6, (uint8_t *)buffer, (uint16_t)length, HAL_MAX_DELAY);
  }

  /* Play the wake-up sequence only after the robot has safely reached home. */
  if (init_success)
  {
    length = snprintf(buffer, sizeof(buffer),
                      "Robot startup: Playing sentinel animation...\r\n");
    if (length > 0)
    {
      HAL_UART_Transmit(&huart1, (uint8_t *)buffer, (uint16_t)length,
                        HAL_MAX_DELAY);
      HAL_UART_Transmit(&huart6, (uint8_t *)buffer, (uint16_t)length,
                        HAL_MAX_DELAY);
    }

    if (Robot_PlayStartupAnimation())
    {
      length = snprintf(buffer, sizeof(buffer),
                        "[SUCCESS] Animation complete; robot is home.\r\n");
      HAL_GPIO_WritePin(LED_BUILTIN_GPIO_Port, LED_BUILTIN_Pin,
                        GPIO_PIN_RESET);
    }
    else
    {
      length = snprintf(buffer, sizeof(buffer),
                        "[FAILED] Animation stopped: servo error or timeout.\r\n");
      HAL_GPIO_WritePin(LED_BUILTIN_GPIO_Port, LED_BUILTIN_Pin,
                        GPIO_PIN_SET);
    }

    if (length > 0)
    {
      HAL_UART_Transmit(&huart1, (uint8_t *)buffer, (uint16_t)length,
                        HAL_MAX_DELAY);
      HAL_UART_Transmit(&huart6, (uint8_t *)buffer, (uint16_t)length,
                        HAL_MAX_DELAY);
    }
  }

  /* ========== END STARTUP SEQUENCE ========== */

  /*
   * Start the first asynchronous LaserPING measurement. Data records use:
   * LP,timestamp_ms,q1_raw,q2_raw,q3_raw,q4_raw,distance_mm,status
   */
  (void)LaserPING_StartMeasurement();

  while (1)
  {
    DXL_Result base_result;
    DXL_Result shoulder_result;
    DXL_Result elbow_result;
    DXL_Result wrist_result;
    uint16_t laser_distance_mm;
    LaserPING_Status laser_status;

    LaserPING_Process();
    if (LaserPING_GetResult(&laser_distance_mm, &laser_status))
    {
      uint32_t sample_timestamp_ms = HAL_GetTick();
      uint16_t logger_status = 0U;

      /* Zero failed fields rather than publishing a previous sample as new. */
      base_position = 0U;
      shoulder_position = 0U;
      elbow_position = 0U;
      wrist_position = 0U;

      base_result = DXL_GetPresentPosition(&hdxl, BASE_ID, &base_position);
      shoulder_result = DXL_GetPresentPosition(&hdxl, SHOULDER_ID,
                                               &shoulder_position);
      elbow_result = DXL_GetPresentPosition(&hdxl, ELBOW_ID,
                                            &elbow_position);
      wrist_result = DXL_GetPresentPosition(&hdxl, WRIST_ID,
                                            &wrist_position);

      if (laser_status == LASERPING_STATUS_OUT_OF_RANGE)
      {
        logger_status |= LOGGER_STATUS_LASER_OUT_OF_RANGE;
      }
      else if (laser_status == LASERPING_STATUS_SENSOR_ERROR)
      {
        logger_status |= LOGGER_STATUS_LASER_SENSOR_ERROR;
      }
      else if (laser_status != LASERPING_STATUS_VALID)
      {
        logger_status |= LOGGER_STATUS_LASER_TIMEOUT;
      }

      if (base_result != DXL_OK)
      {
        logger_status |= LOGGER_STATUS_BASE_ERROR;
      }
      if (shoulder_result != DXL_OK)
      {
        logger_status |= LOGGER_STATUS_SHOULDER_ERROR;
      }
      if (elbow_result != DXL_OK)
      {
        logger_status |= LOGGER_STATUS_ELBOW_ERROR;
      }
      if (wrist_result != DXL_OK)
      {
        logger_status |= LOGGER_STATUS_WRIST_ERROR;
      }

      if (laser_status != LASERPING_STATUS_VALID)
      {
        laser_distance_mm = 0U;
      }

      length = snprintf(buffer, sizeof(buffer),
                        "LP,%lu,%u,%u,%u,%u,%u,%u\r\n",
                        (unsigned long)sample_timestamp_ms,
                        (unsigned int)base_position,
                        (unsigned int)shoulder_position,
                        (unsigned int)elbow_position,
                        (unsigned int)wrist_position,
                        (unsigned int)laser_distance_mm,
                        (unsigned int)logger_status);

      if (length > 0)
      {
        size_t transmit_length = (size_t)length;
        if (transmit_length >= sizeof(buffer))
        {
          transmit_length = sizeof(buffer) - 1U;
        }

        (void)HAL_UART_Transmit(&huart1, (uint8_t *)buffer,
                                (uint16_t)transmit_length, HAL_MAX_DELAY);
        (void)HAL_UART_Transmit(&huart6, (uint8_t *)buffer,
                                (uint16_t)transmit_length, HAL_MAX_DELAY);
      }

      HAL_GPIO_WritePin(LED_BUILTIN_GPIO_Port, LED_BUILTIN_Pin,
                        (logger_status == 0U) ? GPIO_PIN_RESET : GPIO_PIN_SET);
    }

    /* The driver enforces the sensor's 65 ms minimum measurement interval. */
    (void)LaserPING_StartMeasurement();
    HAL_Delay(1U);
  }
#endif /* SERVO_ONLY_TEST */
}

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


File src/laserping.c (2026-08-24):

#include "laserping.h"

#define LASERPING_GPIO_PORT              GPIOB
#define LASERPING_GPIO_PIN               GPIO_PIN_8
#define LASERPING_TIMER_CHANNEL           TIM_CHANNEL_3
#define LASERPING_TIMER_ACTIVE_CHANNEL    HAL_TIM_ACTIVE_CHANNEL_3
#define LASERPING_TIMER_AF                GPIO_AF2_TIM4

#define LASERPING_TRIGGER_US              5U
#define LASERPING_RESPONSE_TIMEOUT_MS     20U
#define LASERPING_MIN_INTERVAL_MS         65U
#define LASERPING_MIN_VALID_PULSE_US      115U
#define LASERPING_MAX_VALID_PULSE_US      12000U
#define LASERPING_OUT_OF_RANGE_US         13000U
#define LASERPING_SENSOR_ERROR_US         14000U

typedef enum
{
  LASERPING_CAPTURE_IDLE = 0,
  LASERPING_CAPTURE_WAIT_RISE,
  LASERPING_CAPTURE_WAIT_FALL,
  LASERPING_CAPTURE_COMPLETE
} LaserPING_CaptureState;

static TIM_HandleTypeDef *laserping_timer;
static volatile LaserPING_CaptureState capture_state;
static volatile LaserPING_Status result_status;
static volatile uint16_t rising_count;
static volatile uint16_t measured_distance_mm;
static uint32_t trigger_time_ms;
static uint32_t previous_trigger_time_ms;
static bool has_triggered;

static void LaserPING_ConfigureSignalOutput(void)
{
  GPIO_InitTypeDef gpio = {0};

  /* Set ODR low before enabling the output to avoid an unintended pulse. */
  HAL_GPIO_WritePin(LASERPING_GPIO_PORT, LASERPING_GPIO_PIN, GPIO_PIN_RESET);
  gpio.Pin = LASERPING_GPIO_PIN;
  gpio.Mode = GPIO_MODE_OUTPUT_PP;
  gpio.Pull = GPIO_NOPULL;
  gpio.Speed = GPIO_SPEED_FREQ_LOW;
  HAL_GPIO_Init(LASERPING_GPIO_PORT, &gpio);
}

static void LaserPING_ConfigureSignalCapture(void)
{
  GPIO_InitTypeDef gpio = {0};

  gpio.Pin = LASERPING_GPIO_PIN;
  gpio.Mode = GPIO_MODE_AF_PP;
  gpio.Pull = GPIO_NOPULL;
  gpio.Speed = GPIO_SPEED_FREQ_LOW;
  gpio.Alternate = LASERPING_TIMER_AF;
  HAL_GPIO_Init(LASERPING_GPIO_PORT, &gpio);
}

void LaserPING_Init(TIM_HandleTypeDef *timer)
{
  laserping_timer = timer;
  capture_state = LASERPING_CAPTURE_IDLE;
  result_status = LASERPING_STATUS_IDLE;
  rising_count = 0U;
  measured_distance_mm = 0U;
  trigger_time_ms = 0U;
  previous_trigger_time_ms = 0U;
  has_triggered = false;

  LaserPING_ConfigureSignalCapture();
}

bool LaserPING_StartMeasurement(void)
{
  uint32_t now;

  if ((laserping_timer == NULL) ||
      (capture_state == LASERPING_CAPTURE_WAIT_RISE) ||
      (capture_state == LASERPING_CAPTURE_WAIT_FALL) ||
      (capture_state == LASERPING_CAPTURE_COMPLETE))
  {
    return false;
  }

  now = HAL_GetTick();
  if (has_triggered && ((now - previous_trigger_time_ms) < LASERPING_MIN_INTERVAL_MS))
  {
    return false;
  }

  (void)HAL_TIM_IC_Stop_IT(laserping_timer, LASERPING_TIMER_CHANNEL);
  LaserPING_ConfigureSignalOutput();

  /* TIM4 runs at 1 MHz, so one counter tick equals one microsecond. */
  __HAL_TIM_SET_COUNTER(laserping_timer, 0U);
  __HAL_TIM_CLEAR_FLAG(laserping_timer, TIM_FLAG_UPDATE | TIM_FLAG_CC3);
  __HAL_TIM_ENABLE(laserping_timer);
  HAL_GPIO_WritePin(LASERPING_GPIO_PORT, LASERPING_GPIO_PIN, GPIO_PIN_SET);
  while (__HAL_TIM_GET_COUNTER(laserping_timer) < LASERPING_TRIGGER_US)
  {
  }
  HAL_GPIO_WritePin(LASERPING_GPIO_PORT, LASERPING_GPIO_PIN, GPIO_PIN_RESET);
  __HAL_TIM_DISABLE(laserping_timer);

  /* Release SIG and reconnect PB8 to the TIM4_CH3 capture input. */
  LaserPING_ConfigureSignalCapture();
  __HAL_TIM_SET_COUNTER(laserping_timer, 0U);
  __HAL_TIM_SET_CAPTUREPOLARITY(laserping_timer, LASERPING_TIMER_CHANNEL,
                                TIM_INPUTCHANNELPOLARITY_RISING);
  __HAL_TIM_CLEAR_FLAG(laserping_timer, TIM_FLAG_UPDATE | TIM_FLAG_CC3);

  capture_state = LASERPING_CAPTURE_WAIT_RISE;
  result_status = LASERPING_STATUS_BUSY;
  trigger_time_ms = now;
  previous_trigger_time_ms = now;
  has_triggered = true;

  if (HAL_TIM_IC_Start_IT(laserping_timer, LASERPING_TIMER_CHANNEL) != HAL_OK)
  {
    capture_state = LASERPING_CAPTURE_COMPLETE;
    result_status = LASERPING_STATUS_SENSOR_ERROR;
    return false;
  }

  return true;
}

void LaserPING_Process(void)
{
  if (((capture_state == LASERPING_CAPTURE_WAIT_RISE) ||
       (capture_state == LASERPING_CAPTURE_WAIT_FALL)) &&
      ((HAL_GetTick() - trigger_time_ms) > LASERPING_RESPONSE_TIMEOUT_MS))
  {
    (void)HAL_TIM_IC_Stop_IT(laserping_timer, LASERPING_TIMER_CHANNEL);
    capture_state = LASERPING_CAPTURE_COMPLETE;
    result_status = LASERPING_STATUS_TIMEOUT;
  }
}

bool LaserPING_GetResult(uint16_t *distance_mm, LaserPING_Status *status)
{
  if ((capture_state != LASERPING_CAPTURE_COMPLETE) ||
      (distance_mm == NULL) || (status == NULL))
  {
    return false;
  }

  *distance_mm = measured_distance_mm;
  *status = result_status;
  capture_state = LASERPING_CAPTURE_IDLE;
  result_status = LASERPING_STATUS_IDLE;
  return true;
}
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

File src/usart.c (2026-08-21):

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
/* Includes ------------------------------------------------------------------*/
#include "usart.h"

UART_HandleTypeDef huart1;
UART_HandleTypeDef huart2;
UART_HandleTypeDef huart6;

/* USART1 init function */

void MX_USART1_UART_Init(void)
{

  huart1.Instance = USART1;
  huart1.Init.BaudRate = 115200;
  huart1.Init.WordLength = UART_WORDLENGTH_8B;
  huart1.Init.StopBits = UART_STOPBITS_1;
  huart1.Init.Parity = UART_PARITY_NONE;
  huart1.Init.Mode = UART_MODE_TX_RX;
  huart1.Init.HwFlowCtl = UART_HWCONTROL_NONE;
  huart1.Init.OverSampling = UART_OVERSAMPLING_16;
  if (HAL_UART_Init(&huart1) != HAL_OK)
  {
    Error_Handler();
  }
}
/* USART2 init function */

void MX_USART2_UART_Init(void)
{

  huart2.Instance = USART2;
  /* AX-series factory-default bus speed. */
  huart2.Init.BaudRate = 1000000;
  huart2.Init.WordLength = UART_WORDLENGTH_8B;
  huart2.Init.StopBits = UART_STOPBITS_1;
  huart2.Init.Parity = UART_PARITY_NONE;
  huart2.Init.Mode = UART_MODE_TX_RX;
  huart2.Init.HwFlowCtl = UART_HWCONTROL_NONE;
  huart2.Init.OverSampling = UART_OVERSAMPLING_16;
  if (HAL_UART_Init(&huart2) != HAL_OK)
  {
    Error_Handler();
  }
}

/* USART6 init function */

void MX_USART6_UART_Init(void)
{
  huart6.Instance = USART6;
  huart6.Init.BaudRate = 115200;
  huart6.Init.WordLength = UART_WORDLENGTH_8B;
  huart6.Init.StopBits = UART_STOPBITS_1;
  huart6.Init.Parity = UART_PARITY_NONE;
  huart6.Init.Mode = UART_MODE_TX_RX;
  huart6.Init.HwFlowCtl = UART_HWCONTROL_NONE;
  huart6.Init.OverSampling = UART_OVERSAMPLING_16;
  if (HAL_UART_Init(&huart6) != HAL_OK)
  {
    Error_Handler();
  }
}

void HAL_UART_MspInit(UART_HandleTypeDef* uartHandle)
{

  GPIO_InitTypeDef GPIO_InitStruct = {0};
  if(uartHandle->Instance==USART1)
  {
    /* USART1 clock enable */
    __HAL_RCC_USART1_CLK_ENABLE();

    __HAL_RCC_GPIOB_CLK_ENABLE();
    /**USART1 GPIO Configuration
    PB6     ------> USART1_TX
    PB7     ------> USART1_RX
    */
    GPIO_InitStruct.Pin = GPIO_PIN_6|GPIO_PIN_7;
    GPIO_InitStruct.Mode = GPIO_MODE_AF_PP;
    GPIO_InitStruct.Pull = GPIO_NOPULL;
    GPIO_InitStruct.Speed = GPIO_SPEED_FREQ_VERY_HIGH;
    GPIO_InitStruct.Alternate = GPIO_AF7_USART1;
    HAL_GPIO_Init(GPIOB, &GPIO_InitStruct);

  }
  else if(uartHandle->Instance==USART2)
  {
    /* USART2 clock enable */
    __HAL_RCC_USART2_CLK_ENABLE();

    __HAL_RCC_GPIOA_CLK_ENABLE();
    /**USART2 GPIO Configuration
    PA2     ------> USART2_TX
    PA3     ------> USART2_RX
    */
    GPIO_InitStruct.Pin = GPIO_PIN_2|GPIO_PIN_3;
    GPIO_InitStruct.Mode = GPIO_MODE_AF_PP;
    GPIO_InitStruct.Pull = GPIO_NOPULL;
    GPIO_InitStruct.Speed = GPIO_SPEED_FREQ_VERY_HIGH;
    GPIO_InitStruct.Alternate = GPIO_AF7_USART2;
    HAL_GPIO_Init(GPIOA, &GPIO_InitStruct);

  }
  else if(uartHandle->Instance==USART6)
  {
    /* USART6 clock enable */
    __HAL_RCC_USART6_CLK_ENABLE();

    __HAL_RCC_GPIOA_CLK_ENABLE();
    /**USART6 GPIO Configuration
    PA11     ------> USART6_TX
    PA12     ------> USART6_RX
    */
    GPIO_InitStruct.Pin = GPIO_PIN_11|GPIO_PIN_12;
    GPIO_InitStruct.Mode = GPIO_MODE_AF_PP;
    GPIO_InitStruct.Pull = GPIO_NOPULL;
    GPIO_InitStruct.Speed = GPIO_SPEED_FREQ_VERY_HIGH;
    GPIO_InitStruct.Alternate = GPIO_AF8_USART6;
    HAL_GPIO_Init(GPIOA, &GPIO_InitStruct);
  }
}

void HAL_UART_MspDeInit(UART_HandleTypeDef* uartHandle)
{

  if(uartHandle->Instance==USART1)
  {
    /* Peripheral clock disable */
    __HAL_RCC_USART1_CLK_DISABLE();

    /**USART1 GPIO Configuration
    PB6     ------> USART1_TX
    PB7     ------> USART1_RX
    */
    HAL_GPIO_DeInit(GPIOB, GPIO_PIN_6|GPIO_PIN_7);

  }
  else if(uartHandle->Instance==USART2)
  {
    /* Peripheral clock disable */
    __HAL_RCC_USART2_CLK_DISABLE();

    /**USART2 GPIO Configuration
    PA2     ------> USART2_TX
    PA3     ------> USART2_RX
    */
    HAL_GPIO_DeInit(GPIOA, GPIO_PIN_2|GPIO_PIN_3);

  }
  else if(uartHandle->Instance==USART6)
  {
    /* Peripheral clock disable */
    __HAL_RCC_USART6_CLK_DISABLE();

    /**USART6 GPIO Configuration
    PA11     ------> USART6_TX
    PA12     ------> USART6_RX
    */
    HAL_GPIO_DeInit(GPIOA, GPIO_PIN_11|GPIO_PIN_12);
  }
}



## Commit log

2026-08-10 Refactor code structure for improved readability and maintainability
    [6dof.kicad_pcb, 6dof.kicad_sch]
2026-08-24 Add the cad folder and Lase Ping feature
    [base_to_shoulder.step, elbow.step, enclosure.step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]
2026-08-27 Continue Laser Ping feature
    [Gripper_Laser_Ping.3mf, Gripper_Laser_Ping.step]

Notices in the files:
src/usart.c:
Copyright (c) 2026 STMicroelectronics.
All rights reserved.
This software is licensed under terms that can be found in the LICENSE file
